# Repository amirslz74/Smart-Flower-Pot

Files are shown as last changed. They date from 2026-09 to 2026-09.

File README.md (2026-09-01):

# Smart Flower Pot

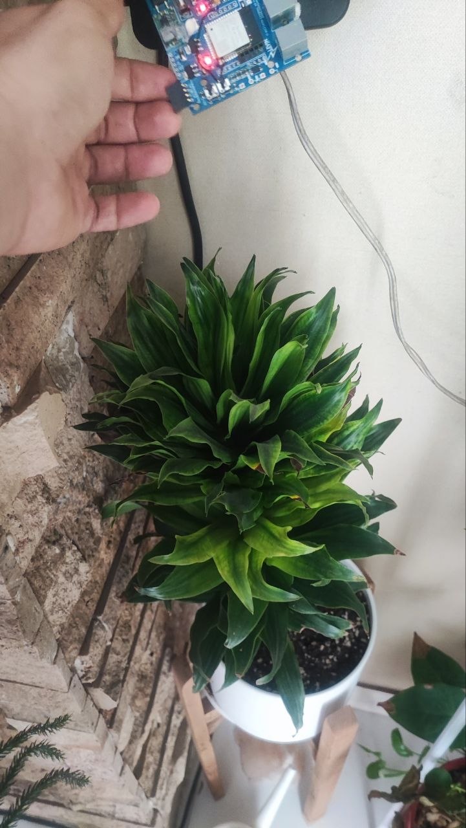
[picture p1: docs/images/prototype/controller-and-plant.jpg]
Four-year home-tested prototype


An open-source ESP32 plant controller designed in EasyEDA, assembled, and tested at home for four years. This repository also provides an inspectable KiCad 10 conversion as a real EasyEDA-to-KiCad case study.

> **Status:** working prototype and reference design. The KiCad conversion preserves the source design, but imported ERC/DRC findings must be reviewed before a new manufacturing run. See [the migration audit](docs/EASYEDA_TO_KICAD.md).

## Highlights

- ESP32 Wi-Fi controller with two relay outputs
- DHT11 temperature and humidity monitoring
- Browser dashboard hosted on SPIFFS
- NTP time synchronization
- Original EasyEDA Standard JSON sources
- Editable KiCad 10 schematic and PCB
- Real assembly and long-term test photographs
- Machine-readable ERC/DRC reports and schematic PDF

## Gallery

| Operating controller | Home test | KiCad conversion |
| --- | --- | --- |
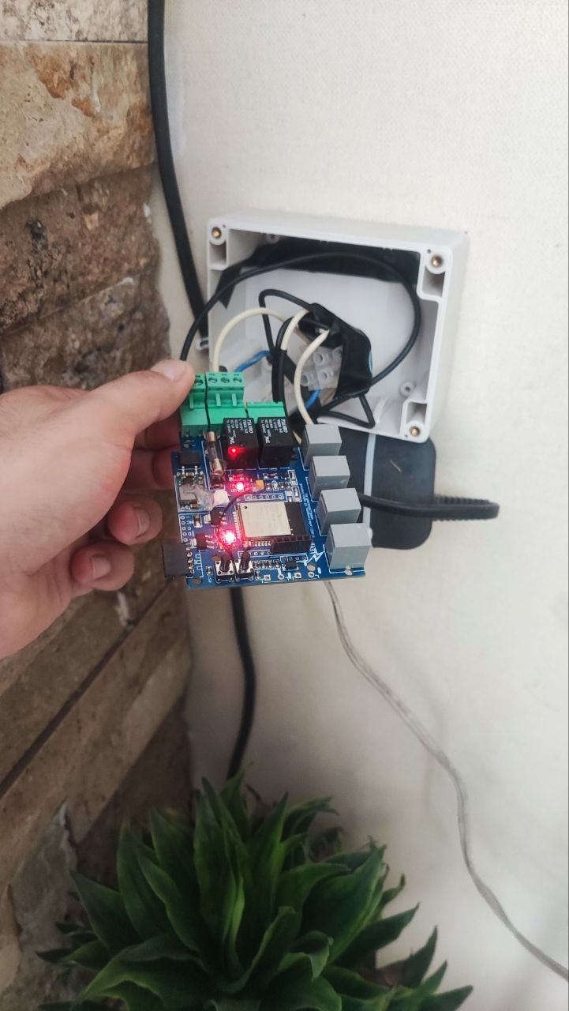
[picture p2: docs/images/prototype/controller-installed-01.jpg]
Controller
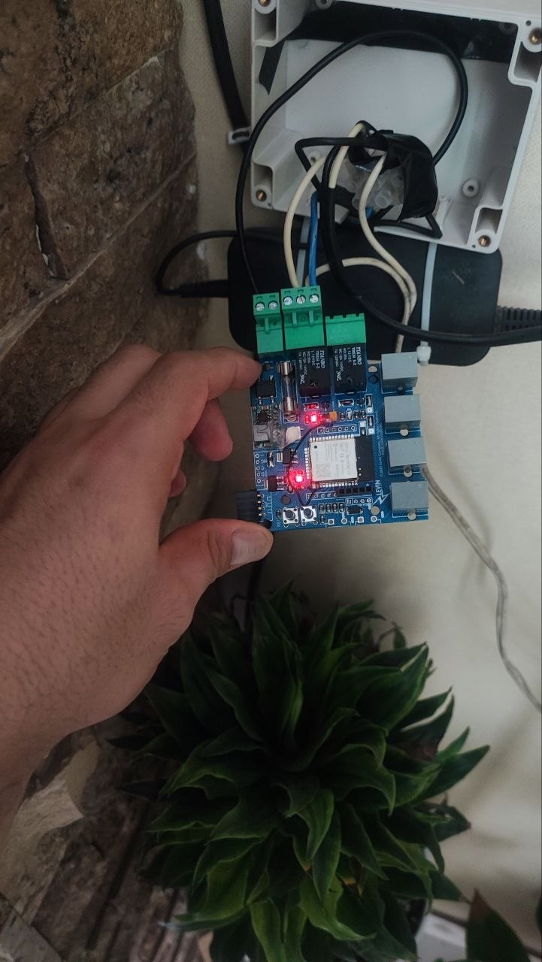
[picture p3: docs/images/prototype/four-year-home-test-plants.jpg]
Plants
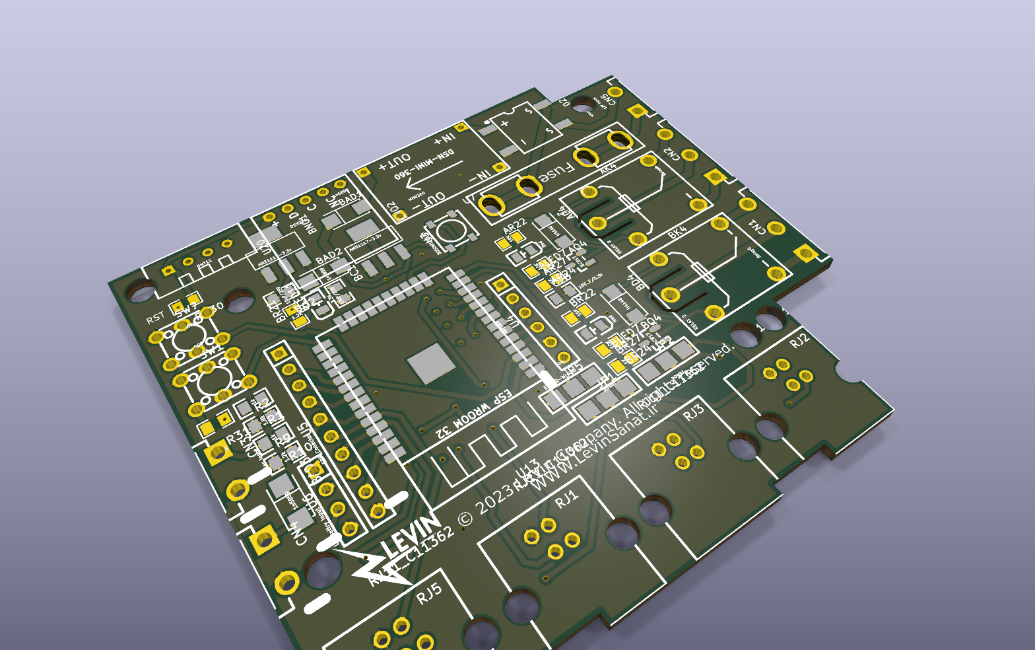
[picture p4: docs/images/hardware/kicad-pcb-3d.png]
PCB render
|  |  |  |

## Repository map

```text
firmware/esp32-web-controller/  Current firmware and web UI
firmware/examples/              Earlier reference experiment
Hardware/easyeda/               Original sources and previews
Hardware/kicad-10/              Editable KiCad 10 project
manufacturing/reports/          KiCad ERC and DRC results
docs/                           Guides and project photographs
```

## Quick start

1. Copy `firmware/esp32-web-controller/secrets.example.h` to `secrets.h`.
2. Add your Wi-Fi details; `secrets.h` is ignored by Git.
3. Install the ESP32 Arduino core, DHT library, and ESPAsyncWebServer dependencies.
4. Upload the `data` directory to SPIFFS, then flash `SmartFlowerPot.ino`.
5. Adjust the static network settings for your installation.

See [firmware instructions](docs/FIRMWARE.md) and the [hardware guide](docs/HARDWARE.md).

## EasyEDA and KiCad

The KiCad version was created with KiCad's native EasyEDA Standard importer, not redrawn from screenshots. The PCB import contains 71 footprints (including mounting-hole objects), 479 track segments, 48 vias, and two zones. After zone refill, KiCad reports zero unconnected PCB items.

Automatic conversion is not engineering sign-off. Imported library associations, symbol electrical types, silkscreen, courtyard, and design-rule conventions explain the recorded warnings. The reports remain visible so contributors can improve the conversion honestly.

## Safety

Relay contacts may carry dangerous voltages. This educational design has no certification. Disconnect power before handling it; use proper fusing, enclosure, strain relief, creepage, and clearance; and obtain qualified review for mains-voltage use.

## Contributing and license

Issues and pull requests are welcome; read [CONTRIBUTING.md](CONTRIBUTING.md). Hardware and manufacturing files use the strongly reciprocal [CERN-OHL-S-2.0](LICENSES/CERN-OHL-S-2.0.txt); firmware and documentation use the [MIT License](LICENSES/MIT.txt). See [LICENSE.md](LICENSE.md) for the scope of each license.

The early asynchronous web-server example retains its Random Nerd Tutorials attribution. Any original hardware project used as a basis must also be credited before release.

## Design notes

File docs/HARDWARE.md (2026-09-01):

# Hardware Overview

The design combines an ESP32 Wi-Fi module, two relay channels, environmental-sensor connections, power regulation/protection, and external connectors.

## Files

- Original EasyEDA source: `Hardware/easyeda/source`
- EasyEDA previews: `Hardware/easyeda/previews`
- KiCad 10 project: `Hardware/kicad-10`
- Schematic PDF: `Hardware/kicad-10/exports/SmartFlowerPot_Schematic.pdf`
- Validation reports: `manufacturing/reports`

## Before manufacturing

1. Resolve all KiCad ERC and DRC errors.
2. Verify footprints, pin numbers, polarity, and manufacturer parts.
3. Confirm relay ratings, fuse, copper width, creepage, and clearance.
4. Generate fresh fabrication files only from the reviewed revision.
5. Test first with a current-limited low-voltage supply.

Do not use mains voltage on an exposed assembly. Use a suitable enclosure, strain relief, protective earth where required, over-current protection, and qualified review.

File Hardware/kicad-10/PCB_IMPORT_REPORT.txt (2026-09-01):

Import Report
=============

Source file: PCB_PCB_Baby-Relay-V001_2026-09-01.json
Source format: EasyEDA / JLCEDA Std
Output file: SmartFlowerPot.kicad_pcb

Statistics:
  Footprints: 71
  Tracks: 479
  Vias: 48
  Zones: 2

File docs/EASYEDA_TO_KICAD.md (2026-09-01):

# EasyEDA Standard to KiCad 10 Migration

The original EasyEDA Standard JSON is preserved beside an editable KiCad 10 conversion.

| Artifact | EasyEDA source | KiCad destination |
| --- | --- | --- |
| Schematic | `Hardware/easyeda/source/SmartFlowerPot_Schematic_EasyEDA.json` | `Hardware/kicad-10/SmartFlowerPot.kicad_sch` |
| PCB | `Hardware/easyeda/source/SmartFlowerPot_PCB_EasyEDA.json` | `Hardware/kicad-10/SmartFlowerPot.kicad_pcb` |
| Project | Source document pair | `Hardware/kicad-10/SmartFlowerPot.kicad_pro` |

## Conversion method

1. Preserve the original JSON without editing it.
2. Import the schematic through **File > Import > Non-KiCad Schematic** in KiCad 10.
3. Import the PCB with KiCad 10's native EasyEDA Standard importer.
4. Save both under one project stem, refill zones, and run ERC/DRC.
5. Export a schematic PDF and PCB render for review.
6. Compare connectors, labels, outline, footprints, tracks, vias, and zones with the EasyEDA previews.

## Audit

The PCB importer reported 71 footprints, 479 track segments, 48 vias, and two zones. Zone refill reduced unconnected PCB items to **zero**.

| Check | Result | Meaning |
| --- | ---: | --- |
| PCB unconnected items | 0 | Copper connectivity completes after zone refill |
| PCB DRC findings | 473 | 456 warnings and 17 errors |
| Schematic ERC findings | 310 | 279 warnings and 31 errors |

The PCB findings are dominated by imported silkscreen, text, padstack, and courtyard conventions. The schematic findings are dominated by imported pin types and missing original library associations. Full JSON reports are under `manufacturing/reports`.

These reports are intentionally retained. Before manufacturing, verify every footprint and pin against datasheets, restore library links, review relay isolation and board-edge clearance, and resolve every error. A successful import does not prove manufacturability.

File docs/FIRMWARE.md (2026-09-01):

# Firmware Guide

The Arduino firmware serves a SPIFFS dashboard, reads a DHT11 on GPIO 32, and controls relays on GPIO 14 and GPIO 4.

## Setup

Install the ESP32 Arduino core, DHT library, ESPAsyncWebServer, its asynchronous TCP dependency, and a compatible SPIFFS uploader. Copy `secrets.example.h` to `secrets.h` and replace the example values:

```cpp
#pragma once
#define WIFI_SSID "your-network-name"
#define WIFI_PASSWORD "your-network-password"
```

Adjust the static IP, gateway, DNS, NTP offset, sensor type, and GPIO assignments. Upload `data/` to SPIFFS, flash `SmartFlowerPot.ino`, then open the serial monitor at 115200 baud.

## Limitations

- Relay endpoints have no authentication.
- Network settings are installation-specific.
- Automatic irrigation policy is not implemented.
- Relay startup state should be made explicit for the connected loads.

Do not expose the server directly to the internet; use a trusted, isolated IoT network.

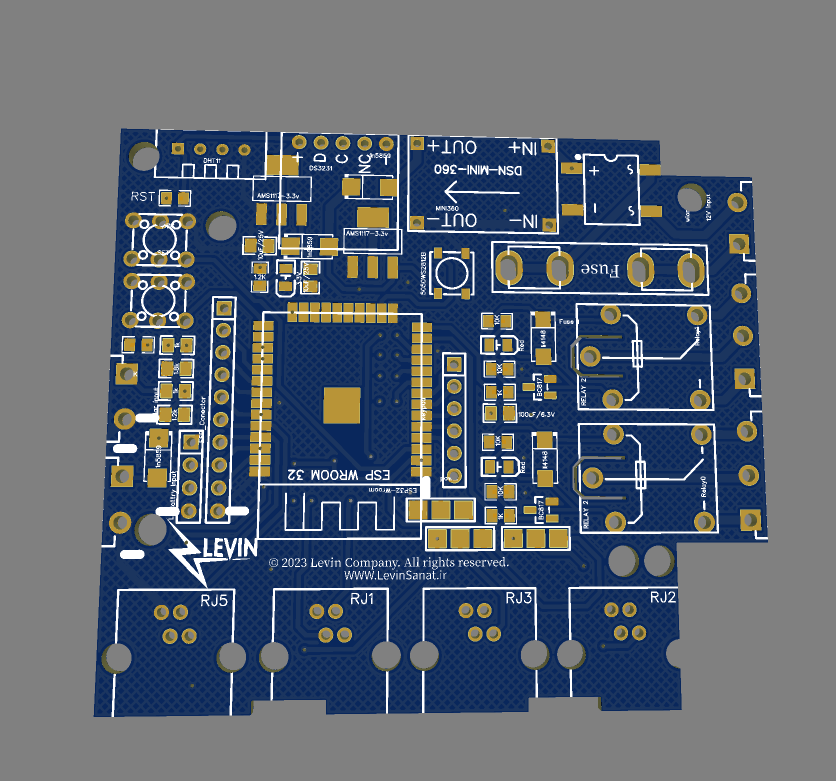
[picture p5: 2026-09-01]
Hardware/easyeda/previews/pcb-layout.png

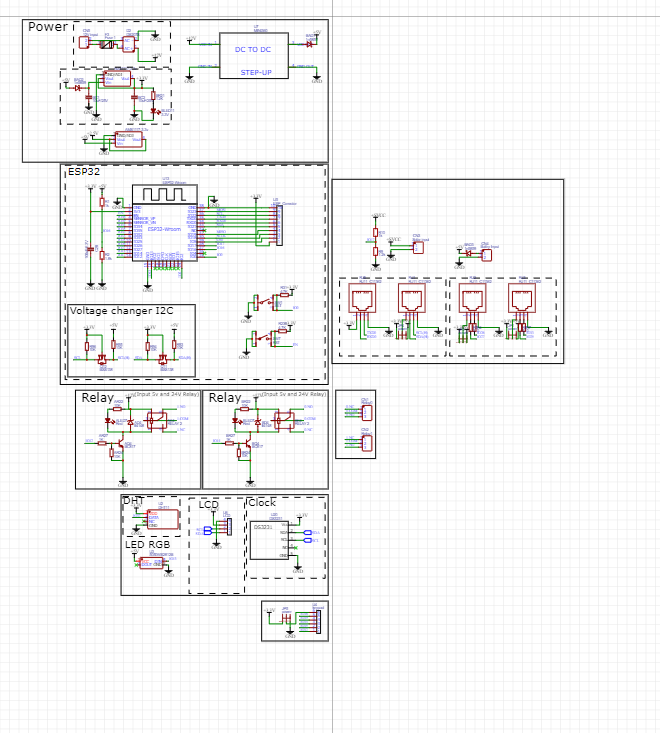
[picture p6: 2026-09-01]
Hardware/easyeda/previews/schematic-overview.png

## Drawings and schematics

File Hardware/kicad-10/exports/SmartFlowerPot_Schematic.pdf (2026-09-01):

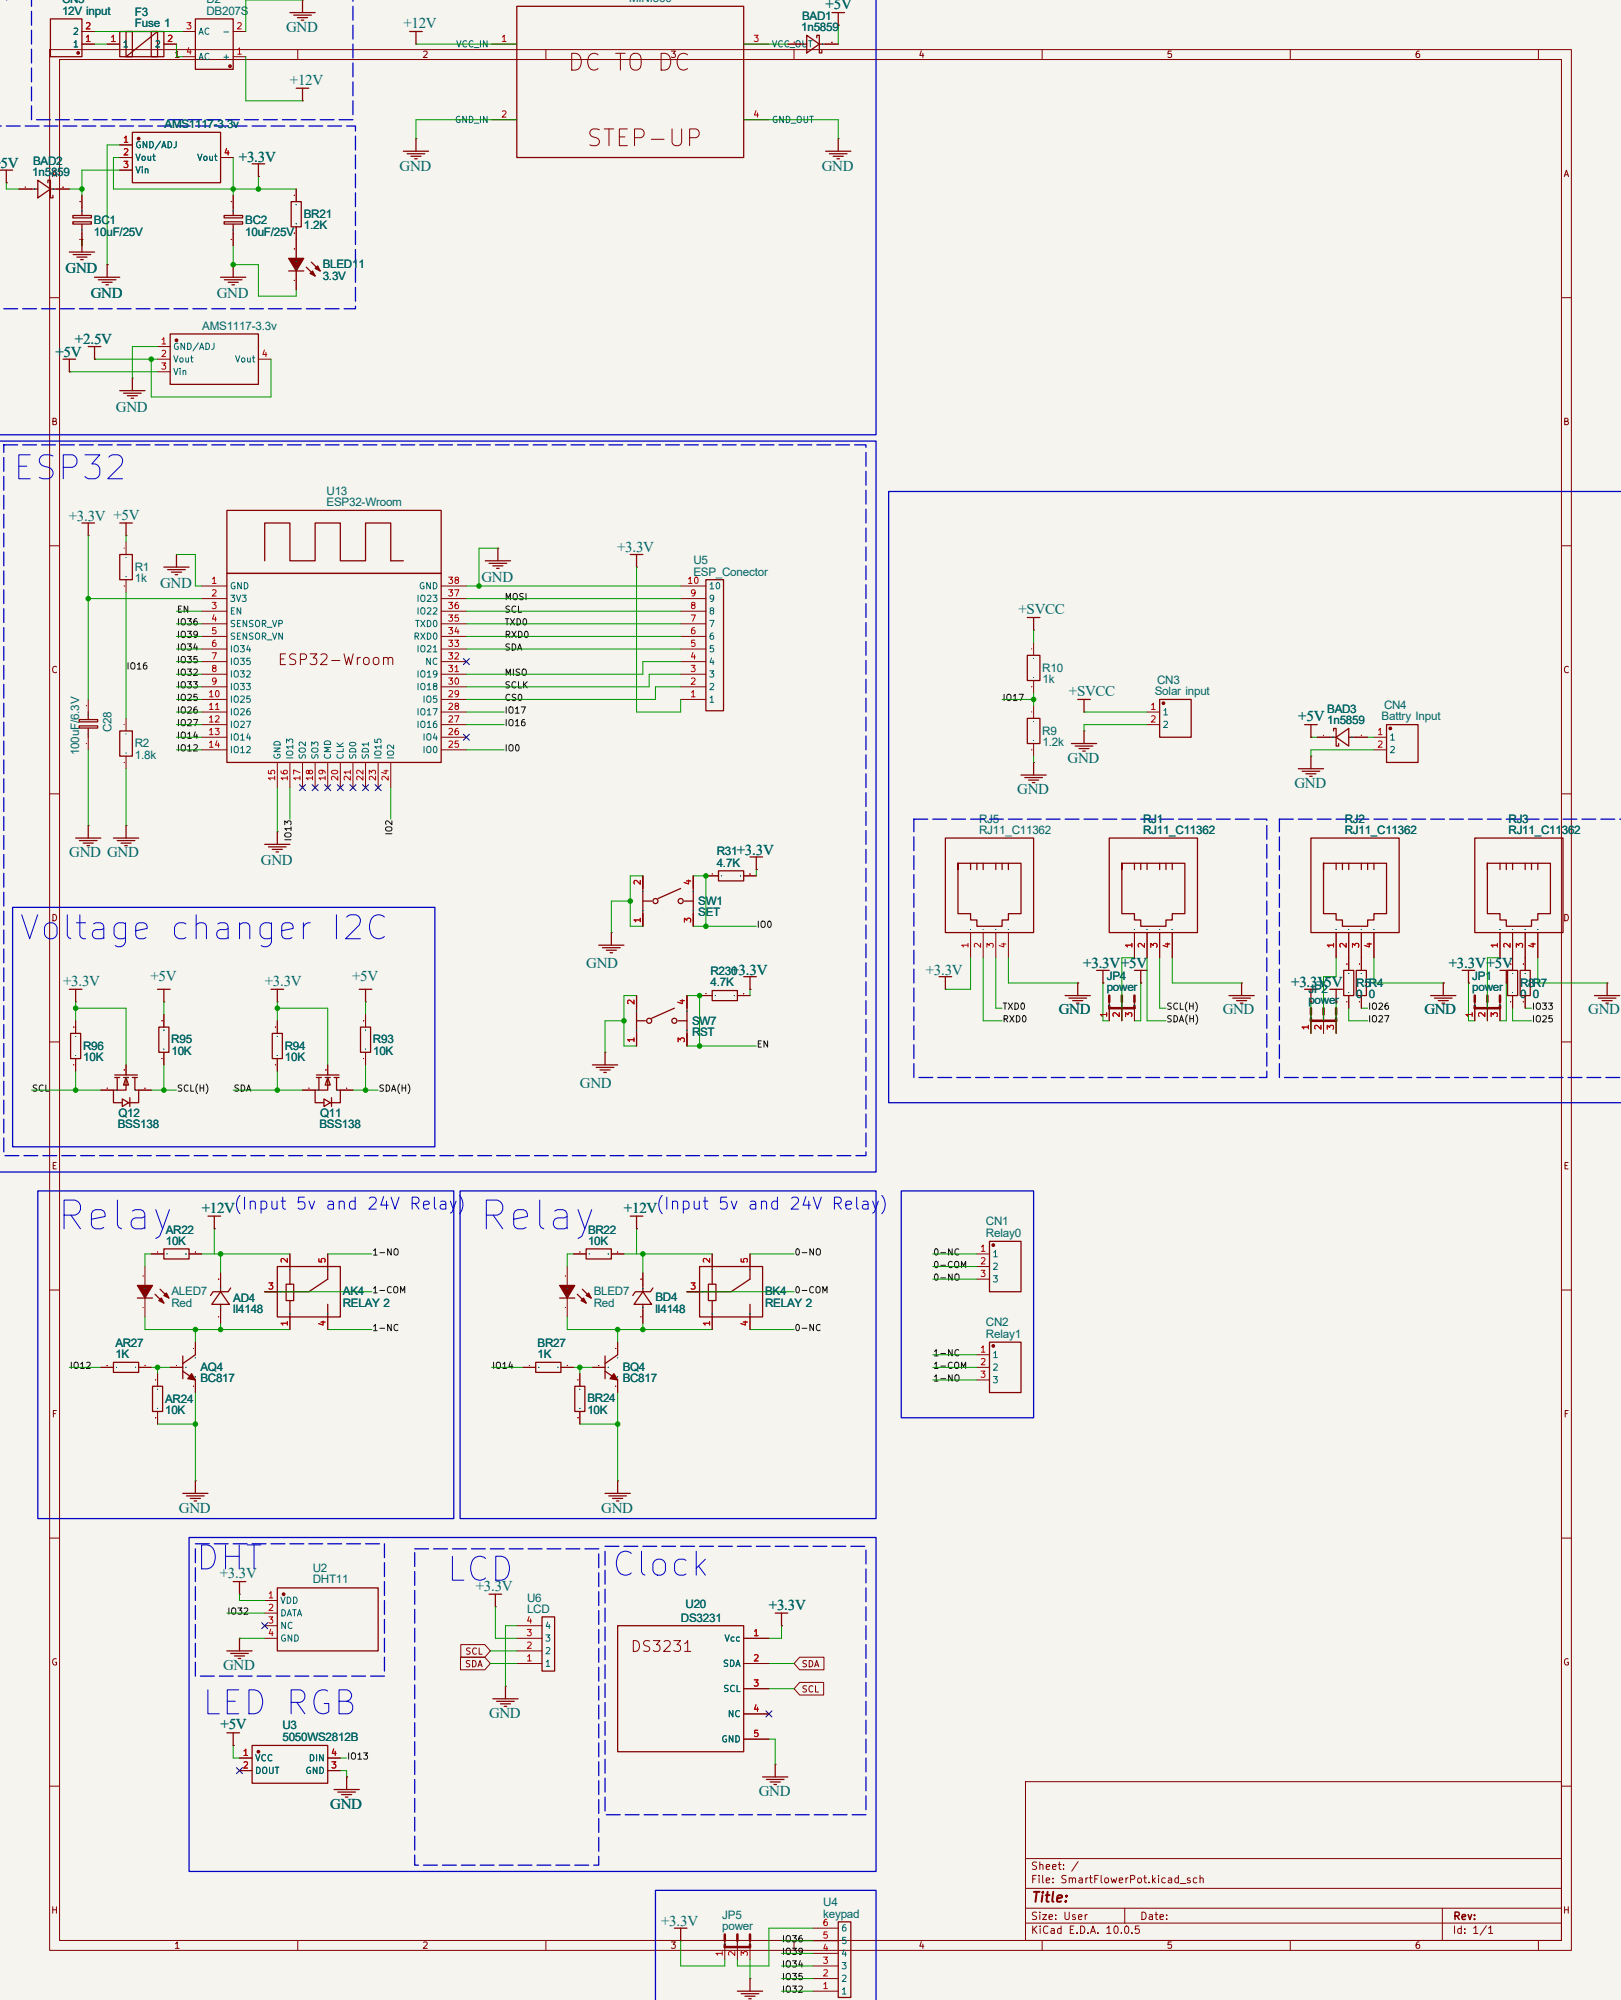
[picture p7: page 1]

SW1 SET | 2 2 1 1

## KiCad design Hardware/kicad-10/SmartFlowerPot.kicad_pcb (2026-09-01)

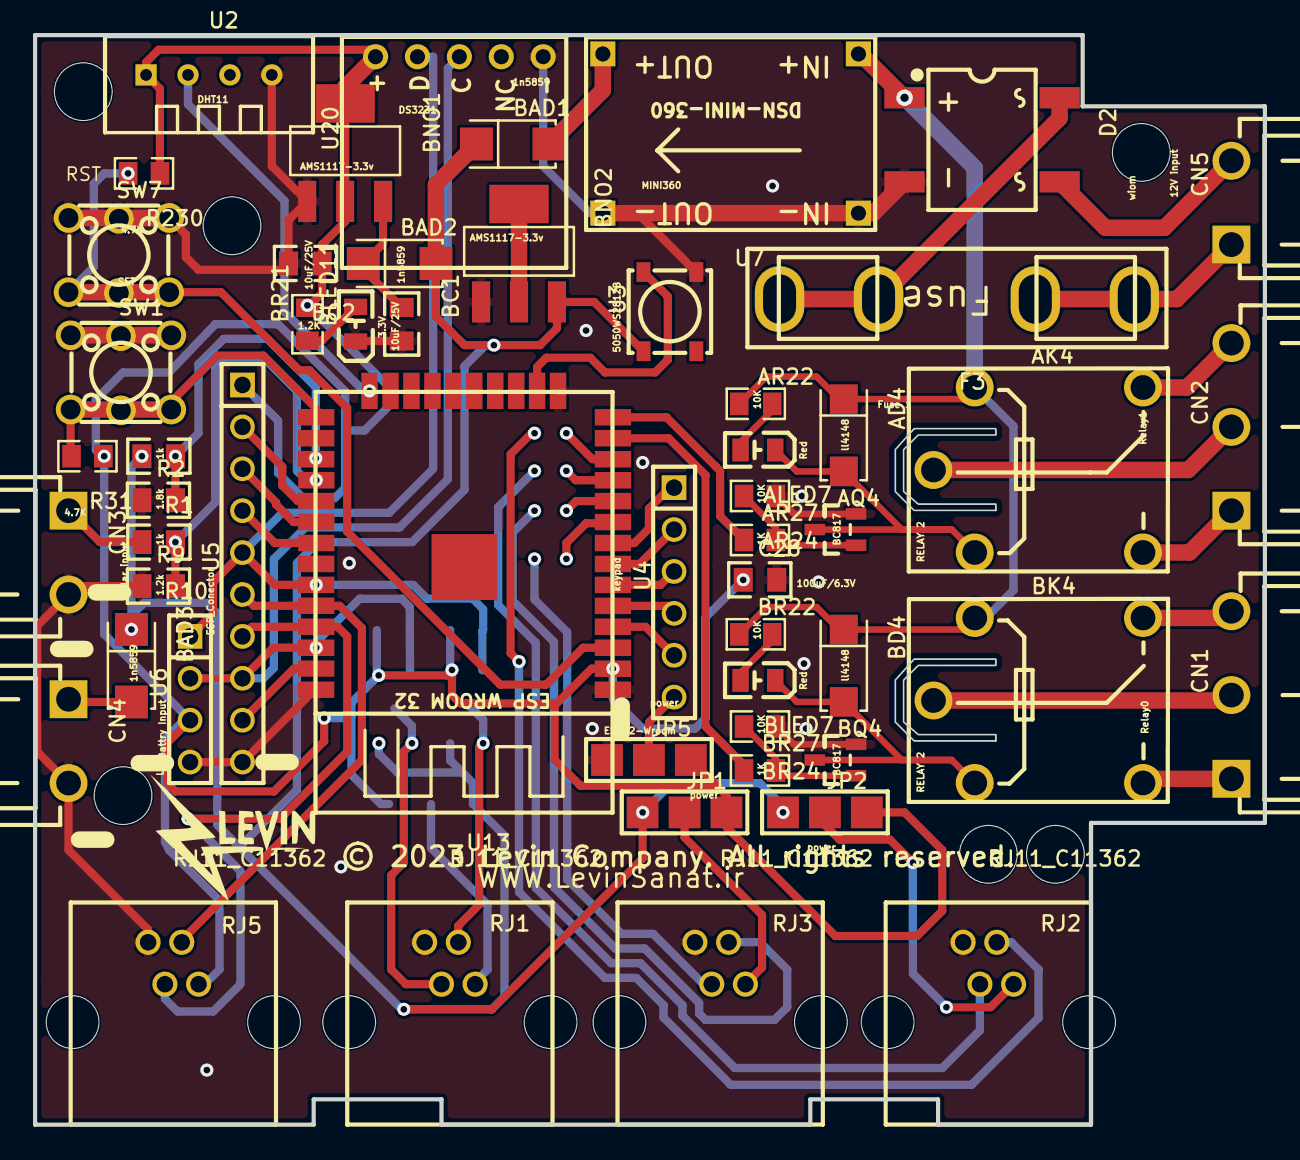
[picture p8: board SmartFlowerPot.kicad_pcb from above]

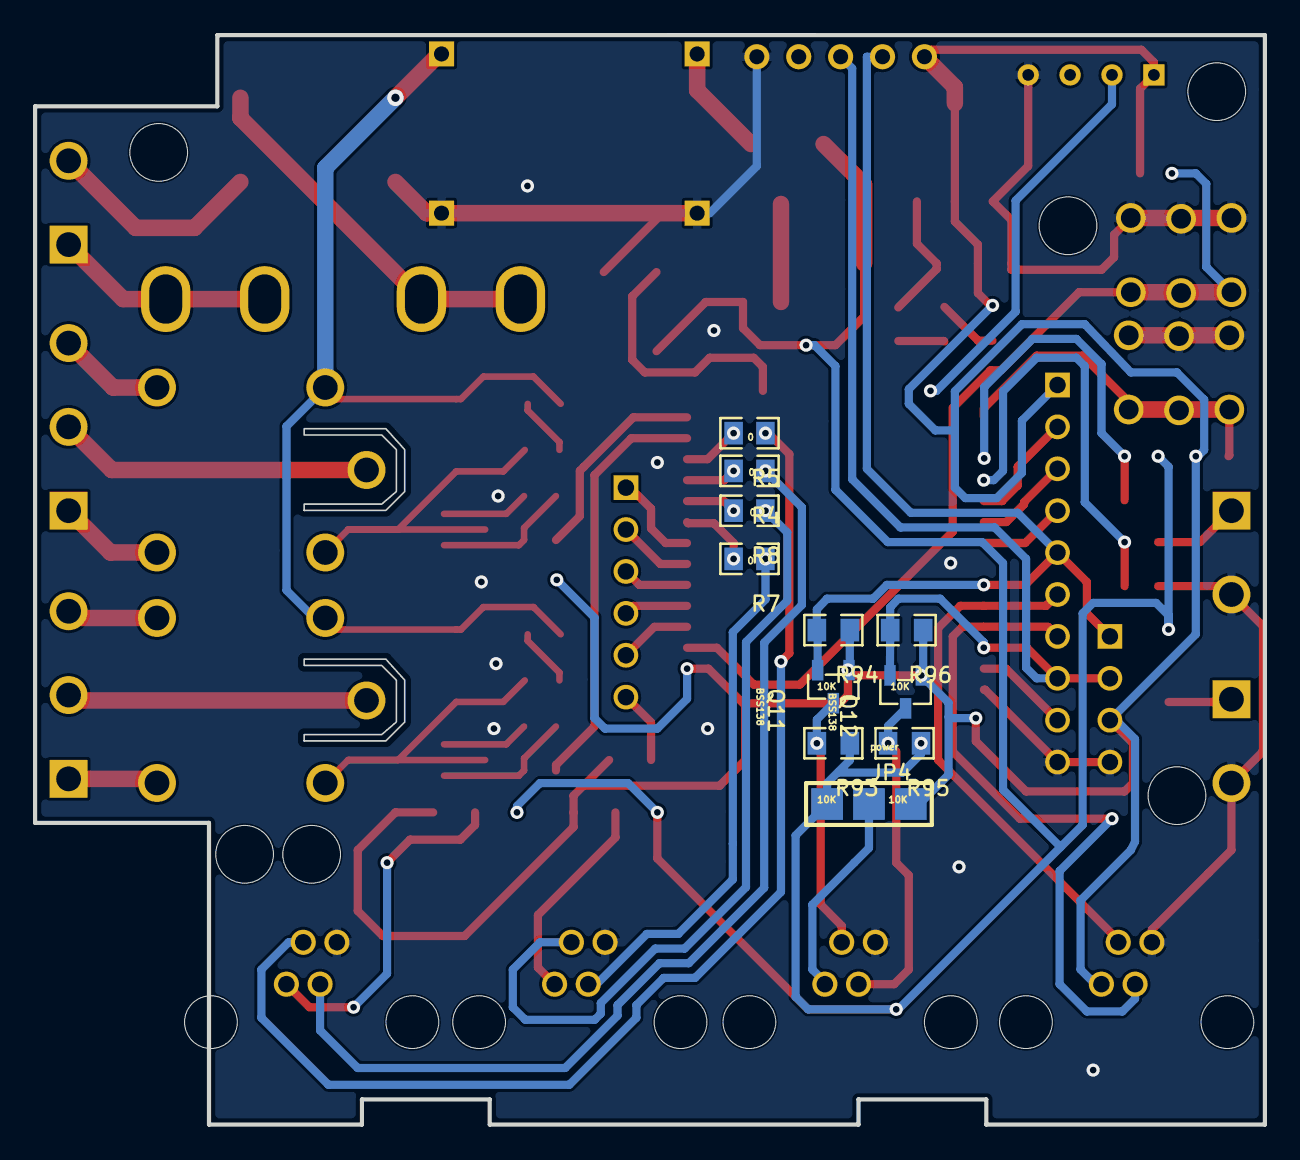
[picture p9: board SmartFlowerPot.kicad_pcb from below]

Board: 2 copper layers, 74.5 x 66.0 mm, 71 parts (11 on the bottom side), 60 nets.

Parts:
AD4: ll4148; SMA_L4.4-W2.6-LS5.0-RD
AK4: RELAY 2; RELAY BABY MILON HLS_T78
ALED7: Red; LED0805-R-RD
AQ4: BC817; SOT-23-3_L2.9-W1.3-P1.90-LS2.4-BR
AR22, AR24: 10K; R0805
AR27: 1K; R0805
BAD1, BAD2, BAD3: 1n5859; SMA_L4.3-W2.6-LS5.1-RD
BC1, BC2: 10uF/25V; 0805
BD4: ll4148; SMA_L4.4-W2.6-LS5.0-RD
BK4: RELAY 2; RELAY BABY MILON HLS_T78
BLED7: Red; LED0805-R-RD
BLED11: 3.3V; LED0805-R-RD
BNO1, BNO2: AMS1117-3.3v; SOT-223-3_L6.5-W3.4-P2.30-LS7.0-BR
BQ4: BC817; SOT-23-3_L2.9-W1.3-P1.90-LS2.4-BR
BR21: 1.2K; R0805
BR22, BR24: 10K; R0805
BR27: 1K; R0805
C28: 100uF/6.3V; 0805
CN1: Relay0; PHONIX 3PIN (5.08MM)
CN2: Relay1; PHONIX 3PIN (5.08MM)
CN3: Solar input; PHONIX 2PIN (5.08MM)
CN4: Battry Input; PHONIX 2PIN (5.08MM)
CN5: 12V input; PHONIX 2PIN (5.08MM)
D2: wiom; SDIP-4_L8.3-W6.4-P5.10-LS9.9-BL
F3: Fuse 1; FUSE
Hole_gge17519: Hole_gge17519
Hole_gge17534: Hole_gge17534
Hole_gge17549: Hole_gge17549
Hole_gge17624: Hole_gge17624
Hole_gge17639: Hole_gge17639
Hole_gge24158: Hole_gge24158
JP1, JP2, JP4, JP5: power; JUMPER 3X1 (PIN= 2.54)
Q11, Q12: BSS138; SOT-23-3_L2.9-W1.3-P1.90-LS2.4-BR
R1, R10: 1k; 0805
R2: 1.8k; 0805
R4, R5, R7, R8: 0; R0805
R9: 1.2k; 0805
R31, R230: 4.7K; R0805
R93, R94, R95, R96: 10K; R0805
RJ1, RJ2, RJ3, RJ5: RJ11_C11362; RJ11-TH_C11362
SW1: SET; SWITCH 4 PIN 6*6*6
SW7: RST; SWITCH 4 PIN 6*6*6
U2: DHT11; SENSOR-TH_DHT11
U3: 5050WS2812B; LED-SMD_5050WS2812B
U4: keypad; 1X6 HEADER (PIN = 2.54)
U5: ESP_Conector; 1X10 HEADER (PIN = 2.54)
U6: LCD; 1X4 HEADER (PIN = 2.54)
U7: MINI360; DSN-MINI-360
U13: ESP32-Wroom; ESP32_WROOM_FOOTPRINT
U20: DS3231

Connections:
0-COM: BK4.3, CN1.2
0-NC: BK4.4, CN1.1
0-NO: BK4.5, CN1.3
1-COM: AK4.3, CN2.2
1-NC: AK4.4, CN2.1
1-NO: AK4.5, CN2.3
+2.5V: BNO2.2, BNO2.4
+3.3V: BC2.1, BNO1.2, BNO1.4, BR21.2, C28.1, JP1.1, JP2.1, JP4.1, JP5.1, Q11.1, Q12.1, R31.1, R94.1, R96.1, R230.1, RJ5.1, U2.1, U5.1, U6.3, U13.2, U20.1
+5V: BAD1.1, BAD2.2, BAD3.1, BNO2.3, JP1.3, JP2.3, JP4.3, R1.2, R93.1, R95.1, U3.1
+12V: AD4.1, AK4.2, AR22.1, BD4.1, BK4.2, BR22.1, D2.1, U7.1
+SVCC: CN3.1, R10.2
AD4_2: AD4.2, AK4.1, ALED7.2, AQ4.3
ALED7_1: ALED7.1, AR22.2
AR27_2: AQ4.1, AR24.2, AR27.2
BD4_2: BD4.2, BK4.1, BLED7.2, BQ4.3
BLED7_1: BLED7.1, BR22.2
BNO1_3: BAD2.1, BC1.1, BNO1.3
BR21_1: BLED11.1, BR21.1
BR27_2: BQ4.1, BR24.2, BR27.2
CN4_1: BAD3.2, CN4.1
CS0: U5.2, U13.29
D2_3: CN5.2, D2.3
EN: R230.2, SW7.3, SW7.4, U13.3
F3_1: CN5.1, F3.1
F3_2: D2.4, F3.2
GND: AQ4.2, AR24.1, BC1.2, BC2.2, BLED11.2, BNO1.1, BNO2.1, BQ4.2, BR24.1, C28.2, CN3.2, CN4.2, D2.2, JP5.3, R2.1, R9.1, RJ1.4, RJ2.4, RJ3.4, RJ5.4, SW1.1, SW1.2, SW7.1, SW7.2, U2.4, U3.3, U5.10, U6.4, U7.2, U7.4, U13.1, U13.15, U13.38, U20.5
IO0: R31.2, SW1.3, SW1.4, U13.25
IO2: U2.2, U13.24
IO12: AR27.1, U13.14
IO13: U3.4, U13.16
IO14: BR27.1, U13.13
IO16: R1.1, R2.2, U13.27
IO17: R9.2, R10.1, U13.28
IO25: R8.2, U13.10
IO26: R4.2, U13.11
IO27: R5.2, U13.12
IO32: U4.1, U13.8
IO33: R7.2, U13.9
IO34: U4.3, U13.6
IO35: U4.2, U13.7
IO36: U4.5, U13.4
IO39: U4.4, U13.5
JP1_2: JP1.2, RJ3.1
JP2_2: JP2.2, RJ2.1
JP4_2: JP4.2, RJ1.1
MISO: U5.4, U13.31
MOSI: U5.9, U13.37
R4_1: R4.1, RJ2.3
R5_1: R5.1, RJ2.2
R7_1: R7.1, RJ3.3
R8_1: R8.1, RJ3.2
RXD0: RJ5.2, U5.6, U13.34
SCL: Q12.2, R96.2, U5.8, U6.2, U13.36, U20.3
SCL(H): Q12.3, R95.2, RJ1.3
SCLK: U5.3, U13.30
SDA: Q11.2, R94.2, U5.5, U6.1, U13.33, U20.2
SDA(H): Q11.3, R93.2, RJ1.2
TXD0: RJ5.3, U5.7, U13.35
U4_6: JP5.2, U4.6
U7_3: BAD1.2, U7.3

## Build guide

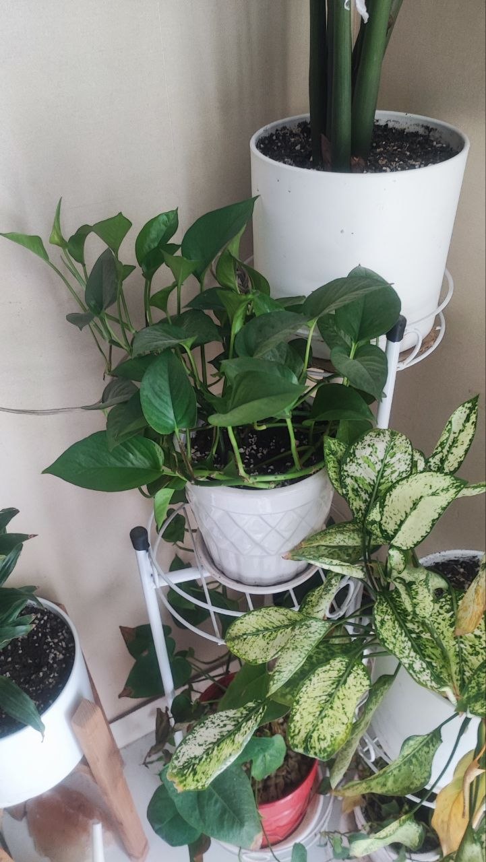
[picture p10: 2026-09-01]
docs/images/prototype/controller-installed-03.jpg

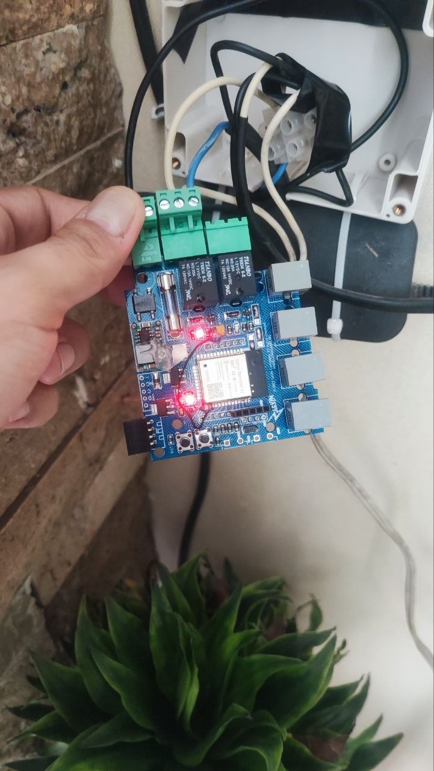
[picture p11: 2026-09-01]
docs/images/prototype/controller-installed-02.jpg

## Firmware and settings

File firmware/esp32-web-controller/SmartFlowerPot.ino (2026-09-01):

// Import required libraries
#include "WiFi.h"
#include "ESPAsyncWebServer.h"
#include "SPIFFS.h"
#include <DHT.h>
#include "time.h"
#include "secrets.h"

// Wi-Fi credentials are kept in secrets.h, which is intentionally not tracked.
const char* ssid = WIFI_SSID;
const char* password = WIFI_PASSWORD;

//config NTP time server
const char* ntpServer = "pool.ntp.org";
const long  gmtOffset_sec = 0;
const int   daylightOffset_sec = 3600;

//DHT sensor configuration 
#define DHTPIN 32     // Digital pin connected to the DHT sensor
// Uncomment the type of sensor in use:
#define DHTTYPE    DHT11     // DHT 11
//#define DHTTYPE    DHT22     // DHT 22 (AM2302)
//#define DHTTYPE    DHT21     // DHT 21 (AM2301)
DHT dht(DHTPIN, DHTTYPE);

// Set Relay GPIO
const int Relay_1 = 14;
const int Relay_2 = 4;
// Stores Relay state
String Relay_1_State;
String Relay_2_State;

// Create AsyncWebServer object on port 80
AsyncWebServer server(80);


String readDHTTemperature() {
  // Sensor readings may also be up to 2 seconds 'old' (its a very slow sensor)
  // Read temperature as Celsius (the default)
  float t = dht.readTemperature();
  // Read temperature as Fahrenheit (isFahrenheit = true)
  //float t = dht.readTemperature(true);
  // Check if any reads failed and exit early (to try again).
  if (isnan(t)) {    
    Serial.println("Failed to read from DHT sensor!");
    return "--";
  }
  else {
    Serial.println(t);
    return String(t);
  }
}


String readDHTHumidity() {
  // Sensor readings may also be up to 2 seconds 'old' (its a very slow sensor)
  float h = dht.readHumidity();
  if (isnan(h)) {
    Serial.println("Failed to read from DHT sensor!");
    return "--";
  }
  else {
    Serial.println(h);
    return String(h);
  }
}

// Replaces placeholder with Relay state value
String processor(const String& var){
  Serial.print(var);
  if(var == "STATE1"){
    if(digitalRead(Relay_1)){
      Relay_1_State = "ON";
    }
    else{
      Relay_1_State = "OFF";
      }
    Serial.println(Relay_1_State);
    return Relay_1_State;
  }
  if(var == "STATE2"){
    if(digitalRead(Relay_2)){
      Relay_2_State = "ON";
    }
    else{
      Relay_2_State = "OFF";
    }
    Serial.println(Relay_2_State);
    return Relay_2_State;
  }
  if(var == "TEMPERATURE"){
    //Serial.print(readDHTTemperature());
    return readDHTTemperature();
  }
  if(var == "HUMIDITY"){
    //Serial.print(readDHTHumidity());
    return readDHTHumidity();
  }
  return String();
}


void printLocalTime(){
  struct tm timeinfo;
  if(!getLocalTime(&timeinfo)){
    Serial.println("Failed to obtain time");
    return;
  }
  Serial.println(&timeinfo, "%A, %B %d %Y %H:%M:%S");
  Serial.print("Day of week: ");
  Serial.println(&timeinfo, "%A");
  Serial.print("Month: ");
  Serial.println(&timeinfo, "%B");
  Serial.print("Day of Month: ");
  Serial.println(&timeinfo, "%d");
  Serial.print("Year: ");
  Serial.println(&timeinfo, "%Y");
  Serial.print("Hour: ");
  Serial.println(&timeinfo, "%H");
  Serial.print("Hour (12 hour format): ");
  Serial.println(&timeinfo, "%I");
  Serial.print("Minute: ");
  Serial.println(&timeinfo, "%M");
  Serial.print("Second: ");
  Serial.println(&timeinfo, "%S");

  Serial.println("Time variables");
  char timeHour[3];
  strftime(timeHour,3, "%H", &timeinfo);
  Serial.println(timeHour);
  char timeWeekDay[10];
  strftime(timeWeekDay,10, "%A", &timeinfo);
  Serial.println(timeWeekDay);
  Serial.println();
}


void setup(){
  // Serial port for debugging purposes
  Serial.begin(115200);
  dht.begin();

  pinMode (Relay_1, OUTPUT);
  pinMode (Relay_2, OUTPUT);


  // Static IP Configuration
  IPAddress staticIP(192, 168, 1, 110);
  IPAddress gateway(192, 168, 1, 1);
  IPAddress subnet(255, 255, 255, 0);
  IPAddress dns(192, 168, 1, 1);
  WiFi.config(staticIP, gateway, subnet, dns);


  // Initialize SPIFFS
  if(!SPIFFS.begin(true)){
    Serial.println("An Error has occurred while mounting SPIFFS");
    return;
  }

  // Connect to Wi-Fi
  WiFi.begin(ssid, password);
  while (WiFi.status() != WL_CONNECTED) {
    delay(1000);
    Serial.println("Connecting to WiFi..");
  }

  // Print ESP32 Local IP Address
  Serial.println(WiFi.localIP());

  // Init and get the time
  configTime(gmtOffset_sec, daylightOffset_sec, ntpServer);
  printLocalTime();

  // Route for root / web page
  server.on("/", HTTP_GET, [](AsyncWebServerRequest *request){
    request->send(SPIFFS, "/index.html", String(), false, processor);
  });
  
  // Route to load style.css file
  server.on("/style.css", HTTP_GET, [](AsyncWebServerRequest *request){
    request->send(SPIFFS, "/style.css", "text/css");
  });

  // Route to set GPIO to HIGH
  server.on("/on1", HTTP_GET, [](AsyncWebServerRequest *request){
    digitalWrite (Relay_1, HIGH);    
    request->send(SPIFFS, "/index.html", String(), false, processor);
  });
  
  // Route to set GPIO to LOW
  server.on("/off1", HTTP_GET, [](AsyncWebServerRequest *request){
    digitalWrite (Relay_1, LOW);
    request->send(SPIFFS, "/index.html", String(), false, processor);
  });
  
  // Route to set GPIO to HIGH
  server.on("/on2", HTTP_GET, [](AsyncWebServerRequest *request){
    digitalWrite (Relay_2, HIGH);    
    request->send(SPIFFS, "/index.html", String(), false, processor);
  });
  
  // Route to set GPIO to LOW
  server.on("/off2", HTTP_GET, [](AsyncWebServerRequest *request){
    digitalWrite (Relay_2, LOW);
    request->send(SPIFFS, "/index.html", String(), false, processor);
  });
  
  server.on("/relay1state", HTTP_GET, [](AsyncWebServerRequest *request){
    request->send_P(200, "text/plain", digitalRead(Relay_1) ? "ON" : "OFF");
  });
  
  server.on("/relay2state", HTTP_GET, [](AsyncWebServerRequest *request){
    request->send_P(200, "text/plain", digitalRead(Relay_2) ? "ON" : "OFF");
  });


  // Route for root / web page
  server.on("/temperature", HTTP_GET, [](AsyncWebServerRequest *request){
    request->send(200, "text/plain", readDHTTemperature().c_str());
  });
  server.on("/humidity", HTTP_GET, [](AsyncWebServerRequest *request){
    request->send(200, "text/plain", readDHTHumidity().c_str());
  });

  
  // Start server
  server.begin();
}
 
void loop(){
  //delay(1000);
  //printLocalTime();
}

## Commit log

2023-11-15 2 Relay done
2026-09-01 feat: open source the Smart Flower Pot hardware
    Organize firmware and hardware sources, add the native KiCad 10 conversion, document the EasyEDA migration and validation results, include project media, remove tracked credentials, and add hardware/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
    [SmartFlowerPot.kicad_pcb, SmartFlowerPot.kicad_sch]

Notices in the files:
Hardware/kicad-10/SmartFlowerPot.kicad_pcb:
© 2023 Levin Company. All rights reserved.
